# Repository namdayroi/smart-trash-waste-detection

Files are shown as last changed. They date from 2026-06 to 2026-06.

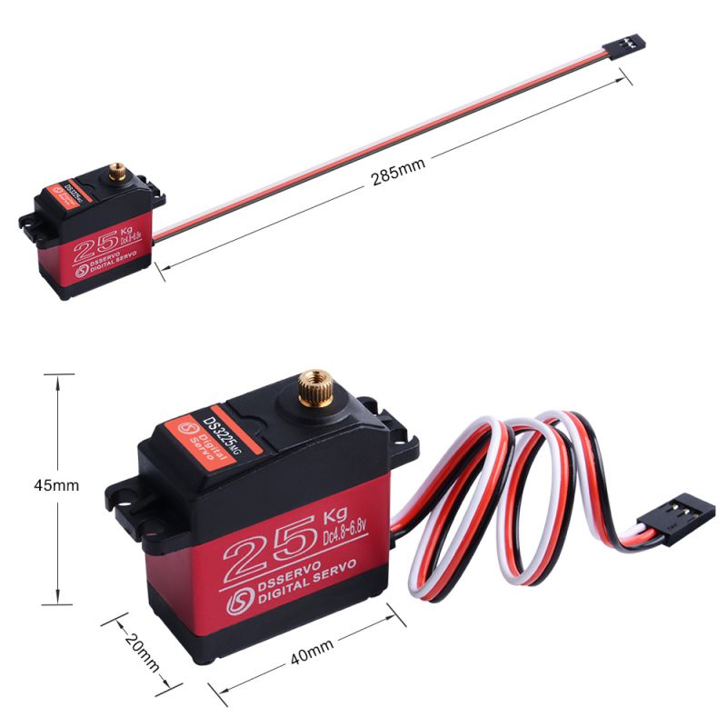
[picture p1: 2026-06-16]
Images/image18.jpeg

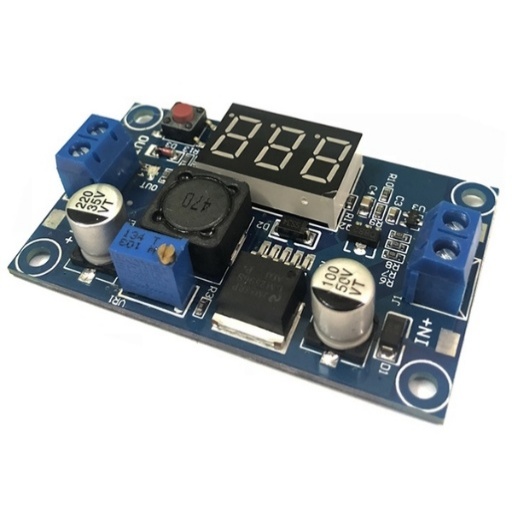
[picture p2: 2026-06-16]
Images/image21.jpeg

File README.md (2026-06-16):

# Hệ thống Phân Loại Rác Tự Động (Smart Trash Classifier System)

Dự án Đồ án tốt nghiệp nghiên cứu, thiết kế và chế tạo hệ thống phân loại rác thông minh tích hợp Thị giác máy tính (Computer Vision), Trí tuệ nhân tạo (YOLOv11m) và Internet of Things (IoT). Hệ thống được triển khai trên kiến trúc phân tán gồm 3 Node kết nối qua mạng Wi-Fi mạng cục bộ (LAN).

---

## 📂 Cấu trúc thư mục dự án (Project Directory Structure)

Dự án được tổ chức một cách khoa học và tối ưu để quản lý cả phần mềm, firmware vi điều khiển, thiết kế phần cứng PCB và tài liệu báo cáo:

```
SmartTrashClassifier/
├── README.md                           # Hướng dẫn chi tiết cài đặt và vận hành hệ thống
├── Images/                             # Tập hợp hình ảnh kết quả thực nghiệm, biểu đồ (tài liệu đồ án)
├── Documentation/                      # Báo cáo thuyết minh và tài liệu thiết kế đồ án
│   └── Graduation_Thesis.docx          # File báo cáo đồ án tốt nghiệp thuyết minh chi tiết
├── Software_PC/                        # Phần mềm xử lý trung tâm và chạy AI trên máy tính
│   ├── run_pc_app.py                   # Script ứng dụng chính (CustomTkinter GUI + YOLO Object Tracking)
│   ├── config.json                     # File cấu hình kết nối, ngưỡng tin cậy AI, danh sách class rác
│   ├── stats.db                        # Cơ sở dữ liệu SQLite lưu lịch sử phân loại rác cục bộ
│   └── system.log                      # Nhật ký (log) ghi nhận lỗi và trạng thái hệ thống
├── Firmware/                           # Chương trình nạp cho các vi điều khiển ESP32
│   ├── Camera_Node/                    # Node ESP32-S3 Cam làm nhiệm vụ truyền dòng video MJPEG
│   │   ├── Camera_Node.ino             # File chương trình chính cho module camera
│   │   ├── app_httpd.cpp               # Cấu hình Web Server truyền hình ảnh chất lượng cao
│   │   ├── camera_index.h              # File chứa mã HTML cấu hình thông số camera
│   │   ├── camera_pins.h               # Định nghĩa sơ đồ chân camera ESP32-S3 EYE
│   │   └── partitions.csv              # Phân vùng bộ nhớ flash (nới rộng phân vùng app)
│   ├── Controller_Node/                # Node ESP32 điều khiển cơ cấu phân loại (Bản nâng cao v3.0)
│   │   └── Controller_Node.ino         # Máy trạng thái điều khiển động cơ bước, servo, và cổng API
│   └── Controller_Node_Simple/         # Node ESP32 điều khiển cơ cấu (Bản cơ bản v1.0 - Dự phòng)
│       └── Controller_Node_Simple.ino  # Code điều khiển cơ bản, kết nối Wi-Fi thủ công
└── Hardware_PCB/                       # Thiết kế sơ đồ nguyên lý và layout mạch in (KiCad)
    ├── THUNGRAC_AI_CAM.kicad_pcb       # Bản vẽ thiết kế mạch in PCB 
    ├── THUNGRAC_AI_CAM.kicad_sch       # Sơ đồ nguyên lý toàn mạch
    ├── THUNGRAC_AI_CAM.kicad_pro       # Quản lý cấu hình dự án KiCad
    ├── THUNGRAC_AI_CAM.kicad_prl       # File lưu trữ cài đặt hiển thị cục bộ
    ├── THUNGRAC_AI_CAM.svg             # Sơ đồ mạch điện xuất ra định dạng ảnh vector
    ├── Library.pretty/                 # Tập hợp footprint linh kiện nội bộ của mạch
    ├── THUNGRAC_AI_CAM-backups/        # Thư mục chứa các file sao lưu tự động của dự án
    └── Libraries/                      # Thư viện mô hình 3D (STEP/WRL) của các linh kiện bên ngoài
        ├── ESP32-S3-DEVKITC-1U-N8R8/   # Thư viện footprint & 3D cho ESP32-S3 DevKit
        ├── LM2596-StepDown/            # Thư viện footprint & 3D cho mạch giảm áp LM2596
        └── TMC2209-Driver/             # Thư viện footprint & 3D cho module Driver TMC2209
```

---

## 🛠️ Sơ đồ Kiến trúc & Luồng hoạt động (System Architecture & Dataflow)

Hệ thống hoạt động theo mô hình luồng khép kín thời gian thực:
1. **Thu thập dữ liệu hình ảnh (Camera Node)**: Module ESP32-S3 Cam thu nhận hình ảnh từ camera OV2640 và truyền phát liên tục dưới dạng luồng MJPEG Stream qua giao thức HTTP ở cổng `81`.
2. **Xử lý trí tuệ nhân tạo (Central PC Node)**: 
   * Máy tính PC kết nối vào luồng stream, giải mã từng khung hình.
   * Áp dụng mô hình **YOLOv11m** được tối ưu hóa để định vị các loại rác thải.
   * Bộ theo dõi đối tượng (**Object Tracking**) gán ID duy nhất cho mỗi vật thể để tránh phát hiện lặp lại.
   * Khi xác định loại rác vượt qua ngưỡng tin cậy (Confidence Threshold), PC gửi một yêu cầu GET HTTP đến `Controller_Node` qua API: `http://<CONTROLLER_IP>/sort?class=<CLASS_ID>`.
   * Ghi nhận lịch sử phân loại vào cơ sở dữ liệu **SQLite** cục bộ và đồng bộ lên **Firebase Cloud**.
3. **Thực thi phân loại (Controller Node)**:
   * Nhận lệnh từ PC, chuyển sang trạng thái phân loại tương ứng.
   * Xoay khay động cơ bước đến vị trí thùng rác tương ứng.
   * Kích hoạt Servo mở cửa sập để giải phóng rác, sau đó đóng cửa và quay lại vị trí ban đầu.

---

## 🔌 1. Sơ đồ kết nối phần cứng và Pinout (`Controller_Node`)

Mạch PCB chính liên kết Node điều khiển với các linh kiện chấp hành. Dưới đây là bảng định nghĩa chân kết nối trên vi điều khiển **ESP32-S3**:

| Linh kiện chấp hành | Chân trên ESP32-S3 | Chức năng chi tiết |
| :--- | :---: | :--- |
| **Servo Motor** (Nắp cửa sập) | `GPIO 4` | Điều chế độ rộng xung (PWM) góc mở từ $105^\circ$ đến $170^\circ$. |
| **Driver Step TMC2209** (Step Pin) | `GPIO 5` | Tạo xung nhịp bước động cơ bước (NEMA 17). |
| **Driver Step TMC2209** (Dir Pin) | `GPIO 6` | Xác định chiều quay động cơ (Thuận/Nghịch). |
| **Driver Step TMC2209** (En Pin) | `GPIO 7` | Cho phép/Vô hiệu hóa driver động cơ (Tiết kiệm điện khi rảnh). |
| **Cảm biến Hall A3144** | `GPIO 15` | Cảm biến từ trường từ nam châm để xác định vị trí góc 0 (Homing). |
| **Đèn LED báo trạng thái** | `GPIO 2` | Nhấp nháy báo hiệu kết nối Wi-Fi hoặc trạng thái máy trạng thái. |

---

## 🧠 2. Máy trạng thái Node điều khiển (`Controller_Node`)

Node điều khiển cơ cấu phân loại được lập trình theo mô hình **Finit State Machine (FSM)** bất đồng bộ, giúp vi điều khiển vẫn xử lý Web Server mượt mà khi động cơ đang quay:

* **`STATE_IDLE`**: Trạng thái nghỉ, liên tục lắng nghe yêu cầu API `/sort` từ PC.
* **`STATE_HOMING`**: Trạng thái tìm điểm gốc. Động cơ bước quay chậm cho đến khi cảm biến Hall phát hiện nam châm tại khay mặc định (Góc 0).
* **`STATE_SORT_MOVING_TO_BIN`**: Xoay động cơ bước một góc tương ứng với nhãn rác nhận được:
  * *Class 0 (Chai nước)*: Quay về góc $0^\circ$ (Vị trí gốc).
  * *Class 1 (Lon nước ngọt)*: Quay về góc $90^\circ$.
  * *Class 2 (Thuốc lá)*: Quay về góc $180^\circ$.
  * *Class 3 (Vỏ kẹo)*: Quay về góc $270^\circ$.
* **`STATE_SORT_SERVO_OPENING`**: Kích hoạt Servo kéo cửa sập để mở khay chứa, cho rác rơi xuống thùng.
* **`STATE_SORT_SERVO_CLOSING`**: Servo quay ngược trở lại để đóng nắp cửa sập an toàn.
* **`STATE_SORT_FINISHING`**: Vô hiệu hóa lực giữ động cơ bước (Disable Stepper) để bảo vệ Driver khỏi bị nóng, đồng thời reset trạng thái về `STATE_IDLE`.

---

## 💻 3. Phần mềm điều khiển trung tâm trên PC (`Software_PC`)

### Thiết lập môi trường Python:
1. Đảm bảo máy tính của bạn đã được cài đặt Python 3.10 trở lên.
2. Di chuyển vào thư mục ứng dụng:
   ```bash
   cd Software_PC
   ```
3. Cài đặt các gói thư viện cần thiết:
   ```bash
   pip install customtkinter opencv-python Pillow requests ultralytics
   ```

### Giao thức Tự động dò tìm thiết bị (UDP Auto-Discovery):
Để thuận tiện khi sử dụng trong môi trường mạng Wi-Fi động (IP thay đổi liên tục), phần mềm PC tích hợp cơ chế tự động tìm kiếm IP của các Node ESP32:
* PC phát (Broadcast) định kỳ chuỗi gói tin `"WHO_IS_TRASH_CTRL"` qua giao thức UDP ở port `8888`.
* Các node ESP32 khi nhận được gói tin này sẽ phản hồi lại chuỗi `"I_AM_TRASH_CTRL|<IP_CỦA_ESP>"`.
* Giao diện PC sẽ tự động bắt lấy IP này và cập nhật vào chương trình chính mà không cần người dùng phải cấu hình IP tĩnh thủ công.

### Chạy ứng dụng:
```bash
python run_pc_app.py
```
* **AI Slider**: Cho phép tinh chỉnh trực tiếp ngưỡng tin cậy nhận diện trên giao diện.
* **Auto Tracking Mode**: Bật tính năng theo dõi vật thể bằng thuật toán tích hợp để tránh gửi trùng lệnh khi vật thể chưa đi qua hết tầm camera.

---

## 🔌 4. Thiết kế mạch PCB (`Hardware_PCB`)

Mạch thiết kế hoàn chỉnh trên phần mềm **KiCad** hỗ trợ nạp chương trình, lọc nhiễu cho động cơ công suất lớn và bảo vệ vi điều khiển:
* Sử dụng nguồn đầu vào 12V (Pin LiPo 3S hoặc Adapter) hạ áp qua Buck LM2596 để cấp dòng 5V ổn định cho hệ thống điều khiển.
* Tích hợp tụ điện chống sụt áp tức thời khi động cơ bước khởi động làm treo ESP32.
* **Tính di động của project**: Các liên kết mô hình 3D linh kiện đã được chuyển sang đường dẫn tương đối sử dụng biến môi trường `${KIPRJMOD}/Libraries/...` thay vì đường dẫn tuyệt đối tĩnh trên ổ đĩa. Nhờ vậy, khi bạn tải thư mục dự án này về bất kỳ máy tính nào khác và mở bằng KiCad, tất cả mô hình linh kiện 3D vẫn sẽ hiển thị chính xác và đầy đủ trong 3D Viewer mà không bị báo lỗi thiếu file 3D.

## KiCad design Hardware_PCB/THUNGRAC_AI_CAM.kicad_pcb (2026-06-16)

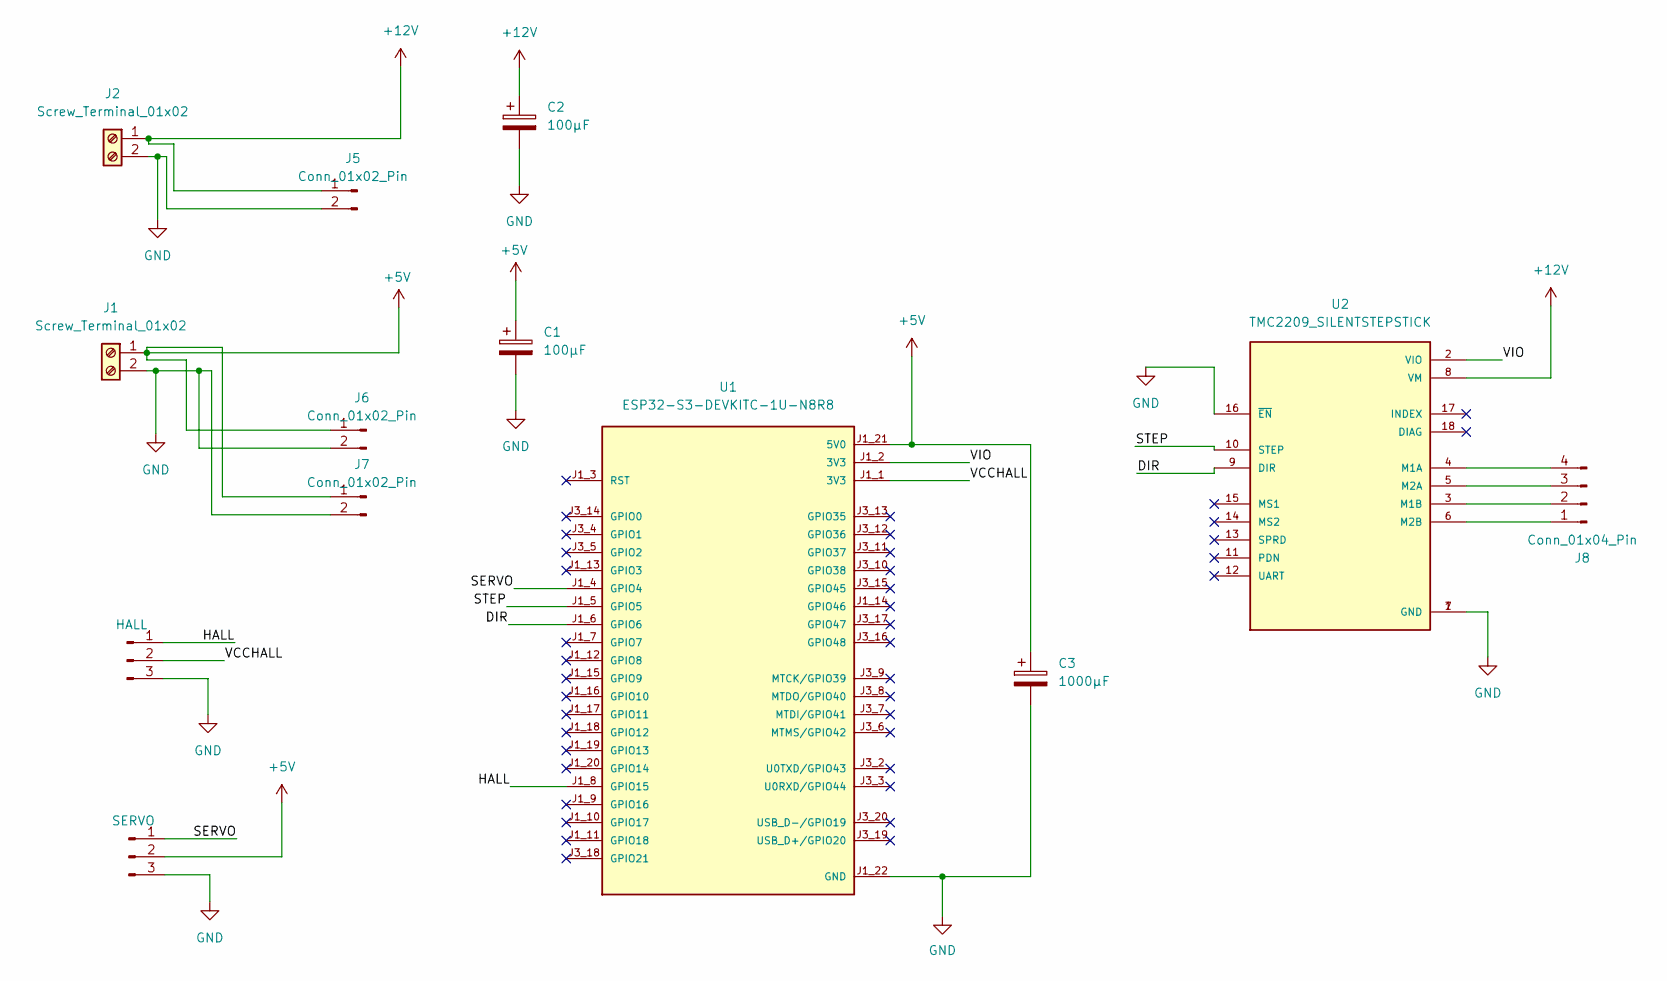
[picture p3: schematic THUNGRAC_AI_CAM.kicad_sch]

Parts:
C1, C2: 100µF; CP_Radial_D8.0mm_P3.50mm
C3: 1000µF; CP_Radial_D8.0mm_P3.50mm
J1, J2: Screw_Terminal_01x02; TerminalBlock_Phoenix_MKDS-1,5-2-5.08_1x02_P5.08mm_Horizont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
J3: HALL; PinHeader_1x03_P2.54mm_Vertical
J4: SERVO; PinHeader_1x03_P2.54mm_Vertical
J5, J6, J7: Conn_01x02_Pin; JST_XH_B2B-XH-A_1x02_P2.50mm_Vertical
J8: Conn_01x04_Pin; JST_XH_B4B-XH-A_1x04_P2.50mm_Vertical
U1: ESP32-S3-DEVKITC-1U-N8R8; MODULE_ESP32-S3-DEVKITC-1U-N8R8; PARTREV 1.1
U2: TMC2209_SILENTSTEPSTICK; MODULE_TMC2209_SILENTSTEPSTICK; PARTREV 1.20

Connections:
+5V: C1.1, C3.1, J1.1, J4.2, J6.1, J7.1, U1.J1_21 (5V0)
+12V: C2.1, J2.1, J5.1, U2.8 (VM)
/DIR: U1.J1_6 (GPIO6), U2.9 (DIR)
/HALL: J3.1, U1.J1_8 (GPIO15)
/SERVO: J4.1, U1.J1_4 (GPIO4)
/STEP: U1.J1_5 (GPIO5), U2.10 (STEP)
/VCCHALL: J3.2, U1.J1_1 (3V3)
/VIO: U1.J1_2 (3V3), U2.2 (VIO)
GND: C1.2, C2.2, C3.2, J1.2, J2.2, J3.3, J4.3, J5.2, J6.2, J7.2, U1.J1_22 (GND), U1.J3_1 (GND), U1.J3_21 (GND), U1.J3_22 (GND), U2.1 (GND), U2.7 (GND), U2.16 (~EN)
unnamed: J8.1, U2.6 (M2B)
unnamed: J8.2, U2.3 (M1B)
unnamed: J8.3, U2.5 (M2A)
unnamed: J8.4, U2.4 (M1A)

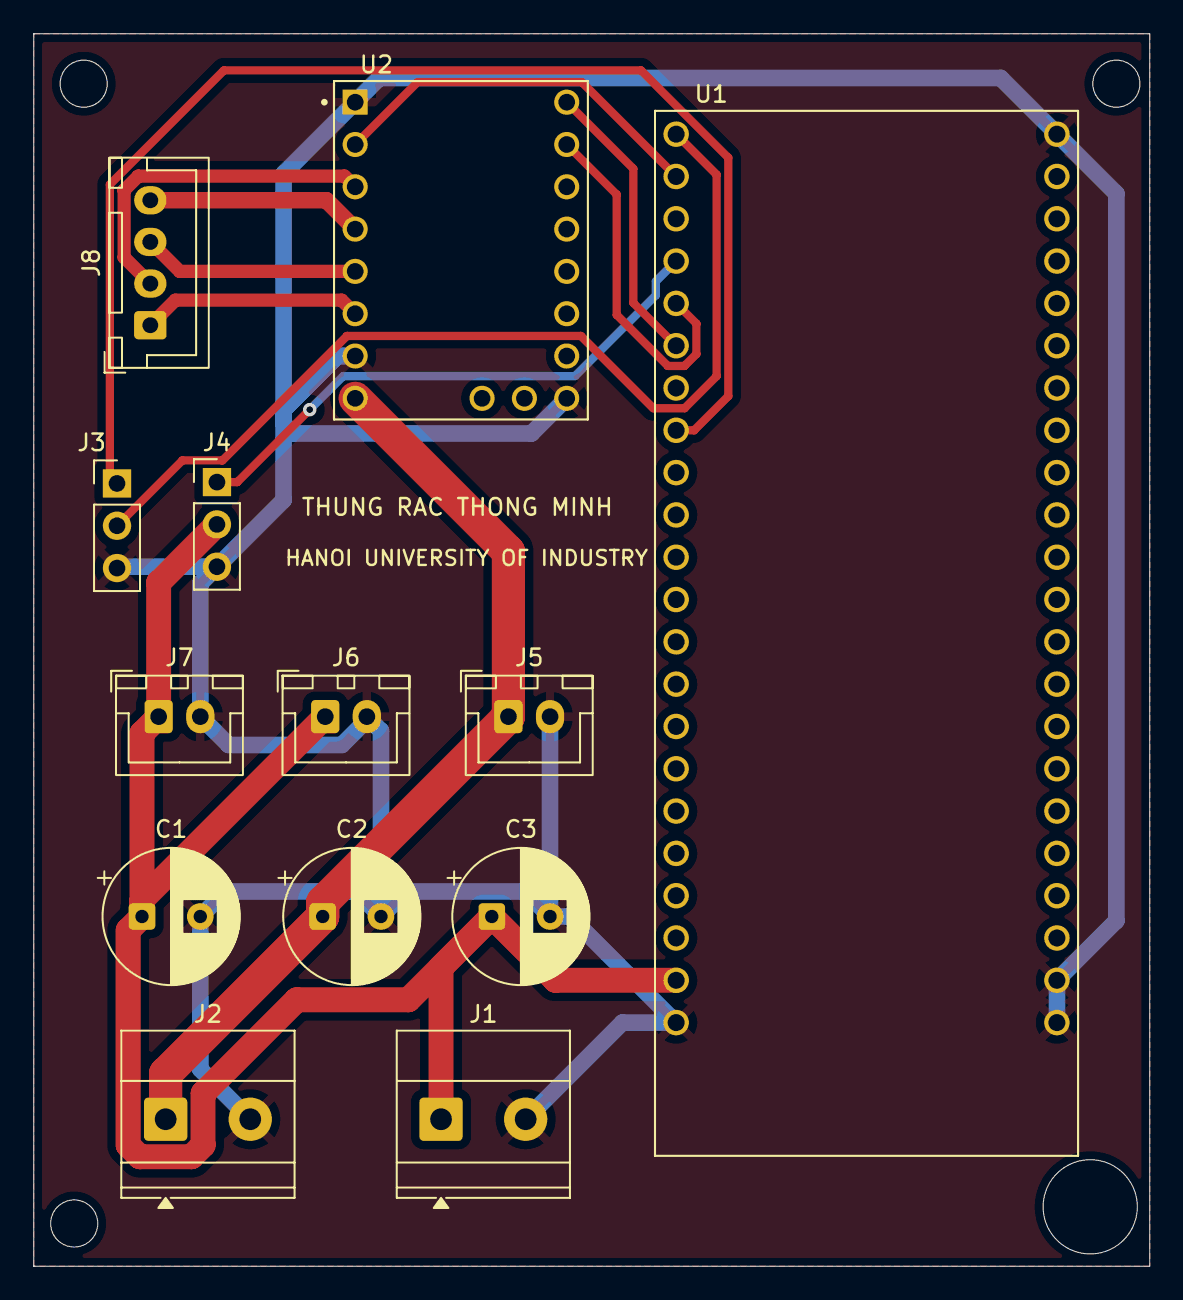
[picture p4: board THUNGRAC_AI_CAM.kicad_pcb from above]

Board: 2 copper layers, 67.0 x 74.0 mm, 13 parts (0 on the bottom side), 13 nets.

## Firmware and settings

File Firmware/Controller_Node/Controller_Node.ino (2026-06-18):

#include <WiFi.h>
#include <WebServer.h>
#include <AccelStepper.h>
#include <ESP32Servo.h>
#include <Preferences.h>
#include <ESPmDNS.h>
#include <WiFiUdp.h>

const char* AP_SSID     = "SmartTrash-CTRL";
const char* AP_PASS     = "12345678";
const char* hostname    = "esp32-controller";
const int   WIFI_TIMEOUT = 15;

const int servoPin = 4;
const int stepPin  = 5;
const int dirPin   = 6;
const int enPin    = 7;
const int hallPin  = 15;
const int ledPin   = 2;

const float calibrationRatio = 150.0 / 130.0;
const long calibratedStepsPerRevolution = (long)(1600 * calibrationRatio);
const long steps90Degrees = calibratedStepsPerRevolution / 4;

#define SERVO_CLOSED  105
#define SERVO_OPEN    170

WiFiUDP udp;
const int UDP_PORT = 8888;
const char* AUTH_USER = "admin";
const char* AUTH_PASS = "SmartTrash2026";

Servo myServo;
AccelStepper stepper(AccelStepper::DRIVER, stepPin, dirPin);
Preferences prefs;
WebServer server(80);

enum SystemState {
  STATE_IDLE,
  STATE_HOMING,
  STATE_SORT_MOVING_TO_BIN,
  STATE_SORT_SERVO_OPENING,
  STATE_SORT_SERVO_CLOSING,
  STATE_SORT_FINISHING
};

SystemState currentState = STATE_IDLE;
int currentClassId = -1;
unsigned long stateTimer = 0;
int servoAngle = SERVO_CLOSED;
bool stepperEnabled = false;

unsigned long totalSorted = 0;
unsigned long sortCount[4] = {0};
const char* classNames[4] = {"Chai nuoc", "Lon nuoc ngot", "Thuoc la", "Vo keo"};
int sortCycleCounter = 0; 
const char CONFIG_PAGE[] PROGMEM = R"rawliteral(
<!DOCTYPE html>
<html>
<head>
  <meta charset="UTF-8">
  <meta name="viewport" content="width=device-width, initial-scale=1">
  <title>SmartTrash Controller - WiFi</title>
  <style>
    * { box-sizing: border-box; margin: 0; padding: 0; }
    body { font-family: 'Segoe UI', sans-serif; background: #0f0f1a; color: #f1f5f9;
           min-height: 100vh; display: flex; align-items: center; justify-content: center; }
    .card { background: #1a1a2e; border-radius: 16px; padding: 32px; width: 90%; max-width: 400px;
            box-shadow: 0 8px 32px rgba(0,0,0,0.4); }
    h1 { text-align: center; font-size: 20px; margin-bottom: 8px; }
    .sub { text-align: center; color: #94a3b8; font-size: 13px; margin-bottom: 24px; }
    .icon { text-align: center; font-size: 48px; margin-bottom: 12px; }
    label { display: block; color: #94a3b8; font-size: 13px; margin-bottom: 6px; margin-top: 16px; }
    input { width: 100%; padding: 12px 16px; border-radius: 8px; border: 1px solid #2d2d4a;
            background: #16213e; color: #f1f5f9; font-size: 15px; outline: none; }
    input:focus { border-color: #6366f1; }
    button { width: 100%; padding: 14px; border-radius: 8px; border: none; background: #22c55e;
             color: white; font-size: 16px; font-weight: bold; cursor: pointer; margin-top: 24px; }
    button:hover { background: #16a34a; }
  </style>
</head>
<body>
  <div class="card">
    <div class="icon"></div>
    <h1>SmartTrash Controller</h1>
    <p class="sub">Cấu hình kết nối WiFi</p>
    <form action="/save" method="GET">
      <label>Tên WiFi (SSID)</label>
      <input type="text" name="ssid" placeholder="Nhập tên WiFi..." required>
      <label>Mật khẩu</label>
      <input type="password" name="pass" placeholder="Nhập mật khẩu WiFi..." required>
      <button type="submit"> Lưu & Kết Nối</button>
    </form>
  </div>
</body>
</html>
)rawliteral";

const char SAVE_PAGE[] PROGMEM = R"rawliteral(
<!DOCTYPE html>
<html>
<head>
  <meta charset="UTF-8">
  <meta name="viewport" content="width=device-width, initial-scale=1">
  <style>
    body { font-family: 'Segoe UI', sans-serif; background: #0f0f1a; color: #f1f5f9;
           min-height: 100vh; display: flex; align-items: center; justify-content: center; }
    .card { background: #1a1a2e; border-radius: 16px; padding: 40px; text-align: center; width: 90%; max-width: 400px; }
    .icon { font-size: 64px; margin-bottom: 16px; }
    h1 { color: #22c55e; margin-bottom: 12px; }
  </style>
</head>
<body>
  <div class="card">
    <div class="icon"></div>
    <h1>Đã lưu thành công!</h1>
    <p>Thiết bị đang khởi động lại...<br>Vui lòng đợi 10 giây.</p>
  </div>
</body>
</html>
)rawliteral";

bool loadSavedWiFi(String &ssid, String &pass) {
  prefs.begin("wifi", true);
  ssid = prefs.getString("ssid", "");
  pass = prefs.getString("pass", "");
  prefs.end();
  return ssid.length() > 0;
}

void clearSavedWiFi() {
  prefs.begin("wifi", false);
  prefs.clear();
  prefs.end();
  Serial.println("[WIFI] Da xoa thong tin WiFi!");
}

bool connectWiFi(const String &ssid, const String &pass) {
  Serial.printf("[WIFI] Dang ket noi: '%s'", ssid.c_str());
  WiFi.mode(WIFI_STA); 
  WiFi.disconnect();
  delay(100);
  WiFi.setHostname(hostname);
  WiFi.begin(ssid.c_str(), pass.c_str());

  int attempts = 0;
  while (WiFi.status() != WL_CONNECTED && attempts < WIFI_TIMEOUT * 2) {
    delay(500);
    Serial.print(".");
    attempts++;
  }
  Serial.println();

  if (WiFi.status() == WL_CONNECTED) {
    Serial.printf("[OK] IP: %s\n", WiFi.localIP().toString().c_str());
    return true;
  }
  Serial.println("[FAIL] Khong the ket noi WiFi!");
  return false;
}

void startConfigPortal() {
  Serial.println("========================================");
  Serial.println("  CHE DO CAU HINH WIFI");
  Serial.printf("  Hotspot: %s\n", AP_SSID);
  Serial.println("  Truy cap: http://192.168.4.1");
  Serial.println("========================================");

  WiFi.mode(WIFI_AP);
  WiFi.softAP(AP_SSID, AP_PASS);
  delay(500);

  WebServer apServer(80);
  apServer.on("/", HTTP_GET, [&apServer]() {
    apServer.send(200, "text/html", CONFIG_PAGE);
  });
  apServer.on("/save", [&apServer]() {
    String ssid = apServer.hasArg("ssid") ? apServer.arg("ssid") : "";
    String pass = apServer.hasArg("pass") ? apServer.arg("pass") : "";
    if (ssid.length() > 0) {
      Preferences p;
      p.begin("wifi", false);
      p.putString("ssid", ssid);
      p.putString("pass", pass);
      p.end();
      apServer.send(200, "text/html", SAVE_PAGE);
      apServer.client().stop(); // Đảm bảo gửi xong web mới restart
      delay(2000);
      ESP.restart();
    } else {
      apServer.send(400, "text/plain", "SSID khong duoc de trong!");
    }
  });
  apServer.begin();

  while (true) {
    apServer.handleClient();
    delay(10);
    if (Serial.available()) {
      if (Serial.readStringUntil('\n').indexOf("RESET") != -1) {
        clearSavedWiFi(); ESP.restart();
      }
    }
  }
}
void enableStepper(bool enable) {
  stepperEnabled = enable;
  digitalWrite(enPin, enable ? LOW : HIGH); // LOW = cấp điện, HIGH = ngắt điện
}

void sendJSON(int code, String jsonBody) {
  server.sendHeader("Access-Control-Allow-Origin", "*");
  server.send(code, "application/json", jsonBody);
}

void handleStatus() {
  if (!server.authenticate(AUTH_USER, AUTH_PASS)) {
    return server.requestAuthentication();
  }

  String json = "{";
  json += "\"status\":\"ok\",";
  json += "\"state\":\"" + String(currentState) + "\",";
  json += "\"busy\":" + String(currentState != STATE_IDLE ? "true" : "false") + ",";
  json += "\"current_class\":" + String(currentClassId) + ",";
  json += "\"current_position\":" + String(stepper.currentPosition()) + ",";
  json += "\"total_sorted\":" + String(totalSorted) + ",";
  json += "\"uptime_ms\":" + String(millis()) + ",";
  json += "\"ip\":\"" + WiFi.localIP().toString() + "\"";
  json += "}";
  sendJSON(200, json);
}

void handleSort() {
  if (!server.authenticate(AUTH_USER, AUTH_PASS)) {
    return server.requestAuthentication();
  }

  if (currentState != STATE_IDLE) {
    sendJSON(503, "{\"status\":\"busy\",\"message\":\"Dang xu ly rac truoc do!\"}");
    return;
  }
  if (!server.hasArg("class")) {
    sendJSON(400, "{\"status\":\"error\",\"message\":\"Thieu tham so class\"}");
    return;
  }

  int class_id = server.arg("class").toInt();
  if (class_id < 0 || class_id > 3) {
    sendJSON(400, "{\"status\":\"error\",\"message\":\"Class khong hop le\"}");
    return;
  }

  currentClassId = class_id;
  long targetPosition = (long)class_id * steps90Degrees;
  enableStepper(true);
  stepper.moveTo(targetPosition);
  currentState = STATE_SORT_MOVING_TO_BIN;
  digitalWrite(ledPin, HIGH);
  
  Serial.printf("\n[SORT] Da nhan lenh Class %d. Dang chay ngam...\n", class_id);

  sendJSON(202, "{\"status\":\"accepted\",\"message\":\"Da dua vao hang doi xu ly\"}");
}

void handleHome() {
  if (!server.authenticate(AUTH_USER, AUTH_PASS)) {
    return server.requestAuthentication();
  }

  if (currentState != STATE_IDLE) {
    sendJSON(503, "{\"status\":\"busy\",\"message\":\"Dang xu ly viec khac!\"}");
    return;
  }
  
  enableStepper(true);
  stepper.setSpeed(500);
  stateTimer = millis();
  currentState = STATE_HOMING;
  digitalWrite(ledPin, HIGH);
  
  sendJSON(202, "{\"status\":\"accepted\",\"message\":\"Bat dau Homing\"}");
}


void processStateMachine() {
  switch (currentState) {
    case STATE_IDLE:
      if (stepperEnabled) {
        enableStepper(false); // Ngắt điện stepper hoàn toàn khi rảnh để tản nhiệt
      }
      break;

    case STATE_HOMING:
      stepper.runSpeed(); // Chạy vận tốc cố định
      if (digitalRead(hallPin) == LOW) { // Đã tìm thấy điểm gốc
        stepper.setCurrentPosition(0);
        stepper.moveTo(0);
        currentState = STATE_IDLE;
        digitalWrite(ledPin, LOW);
        Serial.println("[OK] Homing thanh cong!");
      } else if (millis() - stateTimer > 15000) { // Timeout 15s
        Serial.println("[ERROR] Homing timeout!");
        currentState = STATE_IDLE;
        digitalWrite(ledPin, LOW);
      }
      break;

    case STATE_SORT_MOVING_TO_BIN:
      stepper.run();
      if (stepper.distanceToGo() == 0) {
        myServo.write(SERVO_OPEN);
        stateTimer = millis();
        currentState = STATE_SORT_SERVO_OPENING;
      }
      break;

    case STATE_SORT_SERVO_OPENING:
      if (millis() - stateTimer >= 1000) { // Chờ 1s cho rác rơi
        servoAngle = SERVO_OPEN;
        stateTimer = millis();
        currentState = STATE_SORT_SERVO_CLOSING;
      }
      break;

    case STATE_SORT_SERVO_CLOSING:
      if (millis() - stateTimer >= 10) { // Cứ 10ms đóng 1 độ (Smooth Close)
        servoAngle--;
        myServo.write(servoAngle);
        stateTimer = millis();
        if (servoAngle <= SERVO_CLOSED) {
          stepper.moveTo(0); // Quay khay về vị trí đón rác ban đầu (góc 0)
          currentState = STATE_SORT_FINISHING;
        }
      }
      break;

    case STATE_SORT_FINISHING:
      stepper.run();
      if (stepper.distanceToGo() == 0) {
        totalSorted++;
        sortCount[currentClassId]++;
        sortCycleCounter++;
        currentClassId = -1;
        digitalWrite(ledPin, LOW);
        
        if (sortCycleCounter >= 50) {
           sortCycleCounter = 0;
           Serial.println("[AUTO] Kich hoat Auto-Homing de triet tieu sai so...");
           stepper.setSpeed(500);
           stateTimer = millis();
           currentState = STATE_HOMING;
           digitalWrite(ledPin, HIGH);
        } else {
           currentState = STATE_IDLE;
        }
      }
      break;
  }
}
void setup() {
  Serial.begin(115200);
  
  pinMode(enPin, OUTPUT);
  enableStepper(false); // Ngắt điện mặc định
  pinMode(hallPin, INPUT_PULLUP);
  pinMode(ledPin, OUTPUT); digitalWrite(ledPin, LOW);

  ESP32PWM::allocateTimer(0);
  myServo.setPeriodHertz(50);
  myServo.attach(servoPin, 500, 2500);
  myServo.write(SERVO_CLOSED);

  stepper.setMaxSpeed(2000.0);
  stepper.setAcceleration(1000.0);

  String savedSSID, savedPass;
  if (!loadSavedWiFi(savedSSID, savedPass) || !connectWiFi(savedSSID, savedPass)) {
    startConfigPortal();
  }

  if (MDNS.begin(hostname)) {
    MDNS.addService("http", "tcp", 80);
  }

  if (WiFi.status() == WL_CONNECTED) {
    udp.begin(UDP_PORT);
    Serial.printf("[UDP] Dang lang nghe Port %d cho Auto-Discovery\n", UDP_PORT);
  }

  Serial.println("[HOME] Dang tim diem goc...");
  enableStepper(true);
  stepper.setSpeed(500);

  unsigned long timeout = millis() + 15000;
bool homingOk = false;

while (millis() < timeout) {
  stepper.runSpeed();

  if (digitalRead(hallPin) == LOW) {
    homingOk = true;
    break;
  }

  server.handleClient(); // vẫn cho web server phản hồi trong lúc homing
}

if (homingOk) {
  stepper.setCurrentPosition(0);
  Serial.println("[OK] Homing thanh cong. San sang!");
} else {
  Serial.println("[ERROR] Homing timeout khi khoi dong. Kiem tra cam bien Hall!");
  stepper.setCurrentPosition(0); 
  
}

enableStepper(false);
  server.on("/sort", HTTP_GET, handleSort);
  server.on("/status", HTTP_GET, handleStatus);
  server.on("/home", HTTP_GET, handleHome);
  server.begin();
}

void loop() {
  server.handleClient();
  processStateMachine(); // Gọi máy trạng thái mỗi chu kỳ

  int packetSize = udp.parsePacket();
  if (packetSize) {
    char packetBuffer[255];
    int len = udp.read(packetBuffer, 255);
    if (len > 0) packetBuffer[len] = 0;
    
    if (strcmp(packetBuffer, "WHO_IS_TRASH_CTRL") == 0) {
      String reply = "I_AM_TRASH_CTRL|" + WiFi.localIP().toString();
      udp.beginPacket(udp.remoteIP(), udp.remotePort());
      udp.print(reply);
      udp.endPacket();
      Serial.println("[UDP] Da phan hoi Auto-Discovery cho PC!");
    }
  }

  static unsigned long lastCheck = 0;
  if (millis() - lastCheck > 30000) {
    lastCheck = millis();
    if (WiFi.status() != WL_CONNECTED) {
      String ssid, pass; loadSavedWiFi(ssid, pass);
      if (!connectWiFi(ssid, pass)) startConfigPortal();
    }
  }

  if (Serial.available()) {
    if (Serial.readStringUntil('\n').indexOf("RESET") != -1) {
      clearSavedWiFi(); ESP.restart();
    }
  }
}

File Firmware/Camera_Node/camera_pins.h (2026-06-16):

#pragma once

#if defined(CAMERA_MODEL_ESP32S3_EYE)
#define PWDN_GPIO_NUM     -1
#define RESET_GPIO_NUM    -1
#define XCLK_GPIO_NUM     15
#define SIOD_GPIO_NUM     4
#define SIOC_GPIO_NUM     5

#define Y9_GPIO_NUM       16
#define Y8_GPIO_NUM       17
#define Y7_GPIO_NUM       18
#define Y6_GPIO_NUM       12
#define Y5_GPIO_NUM       10
#define Y4_GPIO_NUM       8
#define Y3_GPIO_NUM       9
#define Y2_GPIO_NUM       11
#define VSYNC_GPIO_NUM    6
#define HREF_GPIO_NUM     7
#define PCLK_GPIO_NUM     13

#define LED_GPIO_NUM      2
#endif

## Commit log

2026-06-16 Initialize project structure and add README.md
    [THUNGRAC_AI_CAM.kicad_pcb, THUNGRAC_AI_CAM.kicad_sch, partitions.csv]
2026-06-18 Fix logic & race bugs in PC application and Controller Node, organize deprecated folders, and add standard .gitignore to untrack temp/cache files
    [Controller_Node.ino, Controller_Node_Simple.ino]
